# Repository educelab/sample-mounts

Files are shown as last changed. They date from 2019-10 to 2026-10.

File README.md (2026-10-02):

# Sample Mounts

3D-printable sample mounts (scroll cases, interface plates, spindles, and
trays) for scanner and beamline data acquisition.

User docs: https://educelab.github.io/sample-mounts/

## Models

Ready-to-print STLs. Variants are named after the parameters they were
rendered with (e.g. `SpindleBase-6.35mm.stl`, `SI Interface Plate - 200mm.stl`).

- **Mount discs and rings.** The standard base (`Generic Mount Disc`, and a
  65 mm version) and the ring it mates with.
- **Interface plates.** Adapt the mount disc to a specific scanner or
  beamline stage (SkyScan 1273, I12.EH1, SI).
- **Spindles.** Spindle bases and stoppers for several rod diameters.

## OpenSCAD

Parametric sources for the models. Parameters are top-level variables and can
be overridden on the command line:

```bash
openscad -o out.stl -D rod_type=2 "OpenSCAD/Spindle Base.scad"
```

Interface plates and spindle bases are built on `Generic Mount Disc*.scad`,
so changing the disc changes all of them.

`Fragment Trays.scad` and `Hanging Frame Case.scad` depend on
`Diamond Interface Plate.scad`, which isn't in this repo, so they won't render
as-is.

## scrollcase

Python generator for split scroll cases fit to a scroll mesh. Requires
[uv](https://docs.astral.sh/uv/):

```bash
cd scrollcase
uv run scrollcase defaults --style educelab.v1 > my-scroll.toml
uv run scrollcase build -c my-scroll.toml -o out/
```

See [Creating a scroll case](docs/creating-scroll-case.md) and the
[config reference](docs/scroll-case-config.md).

## utils

`SpiralLength.cpp` computes the length of an Archimedean spiral for use with
`Spiral Frame.scad`. It needs [GSL](https://www.gnu.org/software/gsl/):

```bash
cmake -S utils -B build && cmake --build build
```

## Docs

The user docs in `docs/` are built with MkDocs and published to GitHub Pages
on every push to `main`. To preview locally:

```bash
uvx --with mkdocs-material --with 'mkdocs<2' mkdocs serve
```

## License

AGPL-3.0. The scroll case's alignment and mesh pipeline are adapted from
[ScrollPrize/villa](https://github.com/ScrollPrize/villa/tree/main/foundation/scrollcase)
(MIT); see `scrollcase/src/scrollcase/LICENSE.villa`.

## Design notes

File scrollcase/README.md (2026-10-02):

# scrollcase

Generates the split honeycomb scroll case (left half with mount disc, right
half, and stand) around a scroll mesh. See
[`docs/creating-scroll-case.md`](../docs/creating-scroll-case.md) for the
workflow and [`docs/scroll-case-config.md`](../docs/scroll-case-config.md)
for every config option.

```bash
uv sync
uv run scrollcase build -c examples/generic.toml -o out/ --preview
uv run pytest
```

`--preview` also writes `<name>-preview.html`, a standalone 3D viewer with
per-part visibility, opacity, and an explode slider (three.js loads from a CDN).

Library use:

```python
from scrollcase import load_config
from scrollcase.pipeline import build

result = build(load_config("my-scroll.toml"), "out/")
```

## How it works

1. **Mesh stage** (`lining.py`, meshlib). Decimate and optionally smooth the
   scroll, fit the smallest enclosing cylinder, and rotate the scroll's wide
   direction into the split plane. Offset by `lining_offset` to get the
   cavity, split it at Y=0, extrude each half toward the split to remove
   undercuts, then offset by `wall_thickness` to get the lining wall.
2. **B-rep stage** (`case.py`, `mount_disc.py`, build123d). Shell, divider,
   mount disc, nubs, escape holes, labels, and stand, ported from the old
   OpenSCAD generator. `scad.py` provides OpenSCAD-style primitives so the
   port stays readable.
3. **Assembly** (`pipeline.py`). Each half is `(body ∪ wall) − cavity`.

meshlib's wheel bundles its own OpenCASCADE, which conflicts with
build123d's and crashes when both load in one process. The pipeline runs the
B-rep stage in `brep_worker` subprocesses and exchanges STLs. Don't import
`case` or build123d anywhere that imports `lining`.

`mount_disc.py` mirrors `OpenSCAD/Generic Mount Disc*.scad`, which the
interface plates and spindle bases still use. Keep them in sync.

`villa.2026-10` is checked against upstream's own code: run
`scripts/villa_reference.py` in an environment with villa's pinned
dependencies (see its docstring) to regenerate the reference data in
`tests/data/`. See [`docs/villa-2026-10-comparison.md`](../docs/villa-2026-10-comparison.md).

## Attribution

The alignment approach and mesh pipeline are adapted from the
[ScrollPrize/villa](https://github.com/ScrollPrize/villa/tree/main/foundation/scrollcase)
`scrollcase` package (MIT). `alignment.py` and `smallest_circle.py` are
derived from it; see `src/scrollcase/LICENSE.villa`.

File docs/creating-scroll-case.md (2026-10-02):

# Creating a scroll case

Scroll cases are generated by the `scrollcase` Python package in
[`scrollcase/`](https://github.com/educelab/sample-mounts/tree/main/scrollcase). Given a scroll mesh, it aligns the scroll,
builds a lining that follows its surface, and wraps the lining in the split
honeycomb case: left half (with mount disc), right half, and assembly stand.

## Requirements

- [uv](https://docs.astral.sh/uv/)
- (Optional) MeshLab, for repairing a mesh that isn't watertight

## Steps

1. **Prepare the mesh.** Any format meshlib reads (PLY, STL, OBJ). It should
   be a single watertight surface. Orientation and position don't matter. If
   it isn't in millimeters, set `scroll.scale`.

2. **Write a config.** Copy
   [`scrollcase/examples/template.toml`](https://github.com/educelab/sample-mounts/blob/main/scrollcase/examples/template.toml)
   next to your mesh:

   ```toml
   --8<-- "template.toml"
   ```

   Set `name`, `scroll.mesh` (relative to the config file), and the label.
   Every option is described in [the config reference](scroll-case-config.md).
   To start from every option instead, print a style's full config:

   ```bash
   cd scrollcase
   uv run scrollcase defaults --style educelab.v1 > my-scroll.toml
   ```

3. **Generate a draft.**

   ```bash
   uv run scrollcase -v build -c my-scroll.toml -o out/ --preview
   ```

   This writes `<name>-L.stl`, `-R.stl`, `-Stand.stl`, and `-Scroll.stl`. The
   scroll STL is the aligned scroll in case coordinates; load it with the
   halves in a viewer to check placement and clearances. `--preview` also
   writes and opens `<name>-preview.html`, which shows every part together.
   Make the halves see-through or explode them apart to check the fit, and
   use **Save snapshot** to save a PNG of the view.

4. **Adjust.**
   - The scroll is auto-aligned to the case axis, with its widest direction
     in the split plane. Use `scroll.rotate` (degrees, XYZ) to adjust it,
     e.g. to put a fragile edge away from the split.
   - Add `nubs.positions` as `[x, z]` pairs. Place them in the divider wall
     between the lining and the shell (the build prints both diameters).
   - `scroll.smoothing` (`"denoise"` or `"shrink_expand"`) simplifies a very
     detailed lining. Smoothing never cuts into the scroll.

5. **Print.** Overhang removal (on by default) extrudes each half's cavity
   toward the split, so the scroll can be lowered straight into either half
   without catching on the lining.

## What changed from the OpenSCAD generator

The manual MeshLab/MeshMixer lining steps, `modelRotate`/`modelTranslate`
positioning, and slow iterative overhang removal are now automatic. The case
design and parameters are the same; parameter names are snake_case.

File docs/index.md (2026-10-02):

# Sample Mounts

3D-printable sample mounts (scroll cases, interface plates, spindles, and
trays) for scanner and beamline data acquisition. Source and models are on
[GitHub](https://github.com/educelab/sample-mounts).

- **Models.** Ready-to-print STLs are in
  [`Models/`](https://github.com/educelab/sample-mounts/tree/main/Models).
- **OpenSCAD.** Parametric sources for most models are in
  [`OpenSCAD/`](https://github.com/educelab/sample-mounts/tree/main/OpenSCAD).
  Parameters are top-level variables and can be overridden with `-D`:

    ```bash
    openscad -o out.stl -D rod_type=2 "OpenSCAD/Spindle Base.scad"
    ```

- **Scroll cases.** Split scroll cases fit to a scroll mesh are generated by
  the `scrollcase` Python package. Start with
  [Creating a scroll case](creating-scroll-case.md), then see the
  [config reference](scroll-case-config.md) for every option.

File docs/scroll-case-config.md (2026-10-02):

# Scroll case config reference

Scroll cases are configured with a TOML file passed to `scrollcase build -c`.
Every key is optional; anything left out comes from the config's style
preset. Print a style's complete config:

```bash
uv run scrollcase defaults --style educelab.v1 > my-scroll.toml
```

Unknown keys are an error, so typos don't silently fall back to defaults.
Combinations that can't be built are also rejected when the config loads
(see [Valid combinations](#valid-combinations)). Lengths are in millimeters
and angles in degrees.

## Styles

`style` picks a preset of defaults for every key below. Your own values
override the preset key by key, so `[shell] type = "solid"` keeps the rest of
the preset's `[shell]` settings, including its marker rings.

| Style | Description |
|---|---|
| `educelab.v1` | The default: honeycomb shell with floor and lid, flat split, Generic Mount Disc, stand. The former OpenSCAD generator's design. |
| `villa.2026-10` | [ScrollPrize/villa's case](https://github.com/ScrollPrize/villa/tree/main/foundation/scrollcase) at commit `7d6a82c` (2026-10-01): no shell, curved split ending in round posts, square bolted caps with upstream's label layout, kinematic mount disc, 3 mm margins, no stand. |

Components mix freely within the [valid combinations](#valid-combinations),
e.g. villa's caps and kinematic disc around a honeycomb shell:

```toml
style = "educelab.v1"
[split]
type = "curve"
[ends]
type = "caps"
[mount]
type = "kinematic"
[stand]
enabled = false
```

`villa.2026-10` reproduces upstream's case bodies exactly; see the
[comparison](https://github.com/educelab/sample-mounts/blob/main/docs/villa-2026-10-comparison.md). The known differences are all in
the mesh stage: the scroll fit uses a tighter tolerance, the wide-axis
rotation normalizes its vector before taking the angle, `voxel_size` is
absolute (upstream uses 0.4% of the mesh diagonal), and `"denoise"`
smoothing uses `smoothing_amount` (upstream ignores its strength setting).

Released styles never change, so a config rebuilds the same case for as
long as it names the same style. A design update becomes a new version
(e.g. `educelab.v2`). Omitting `style` means `educelab.v1`, permanently.

**Case coordinates.** The case axis is +Z and the bottom of the shell is
Z=0; the mount disc sits below it, from Z=-12.5 to 0. The halves split on the
XZ plane: the left half (with the mount disc) is on the -Y side and the right
half is on the +Y side.

## Top level

| Key | Default | Description |
|---|---|---|
| `style` | `"educelab.v1"` | Preset to resolve the rest of the config against. See [Styles](#styles). |
| `name` | `"Scroll Case"` | Output file prefix: `<name>-L.stl`, `-R.stl`, `-Stand.stl`, `-Scroll.stl`. Overridden by `--name`. |
| `lining_offset` | `2.0` | Clearance between the scroll surface and the inside of the lining. Also the gap above and below the scroll. |
| `wall_thickness` | `2.0` | Thickness of the lining wall, shell, lid, and half of the divider. The floor is `max(2, wall_thickness)`. |
| `bottom_buffer` | `5.0` | Gap between the floor and the bottom of the lining. |
| `top_buffer` | `5.0` | Gap between the top of the lining and the lid. |
| `internal_gap` | `3.0` | Radial gap between the lining and the inside of the shell. |
| `overhang_removal` | `true` | Extrudes each half's cavity toward the split so the scroll can be lowered straight in. Turn off only to inspect the raw lining. |
| `voxel_size` | `0.4` | Resolution of the lining offsets and overhang removal. Smaller is more faithful but slower and uses more memory; the PHercParis scrolls peaked at 3.5–5 GB at 0.4. |

## `[scroll]`

The input mesh and how it is prepared and placed.

| Key | Default | Description |
|---|---|---|
| `mesh` | none | Scroll mesh (PLY, STL, or OBJ). A relative path is resolved against the config file. Overridden by the positional `mesh` argument. If unset, a generic cylinder is used. |
| `scale` | `1.0` | Multiplies the mesh coordinates. Use it if the mesh isn't in millimeters. |
| `auto_align` | `true` | Fits the smallest cylinder that encloses the scroll, stands the scroll up along +Z with its bottom at Z=0, and turns its widest direction into the split plane. With `false`, the mesh keeps its own orientation (its Z axis becomes the case axis) but is still centered on the axis with its bottom at Z=0. |
| `rotate` | `[0, 0, 0]` | Extra rotation in degrees about the X, then Y, then Z axes, applied after alignment. The scroll is then re-centered on the case axis, so only the orientation changes. Z spins the scroll about the case axis, e.g. `[0, 0, 90]` puts the widest direction across the split instead of in it. X/Y tilt it; the case grows to enclose the tilted scroll. |
| `translate` | `[0, 0, 0]` | Offset applied after re-centering. An X/Y offset deliberately moves the scroll off the case axis, and the case grows to enclose it. Z has no effect, because the scroll is always placed `lining_offset` above the cavity floor. |
| `decimate_max_error` | `0.05` | How far, at most, the simplified input mesh may deviate from the original. |
| `smoothing` | `"none"` | Simplifies a very detailed lining: `"denoise"` or `"shrink_expand"`. The smoothed result is merged with the original, so smoothing never cuts into the scroll. |
| `smoothing_amount` | `2.0` | For `"denoise"`, the smoothing strength (meshlib `gamma`). For `"shrink_expand"`, the shrink/expand distance in mm; larger values round off more detail. |
| `generic_diameter` | `76.0` | Diameter of the generic cylinder used when `mesh` is unset. |
| `generic_height` | `155.0` | Height of the generic cylinder used when `mesh` is unset. |

## `[split]`

The surface the two halves separate along. Every split is a profile
y = f(x) extruded along Z, so from anywhere in a half the scroll can move
straight along Y to the split; overhang removal relies on this.

| Key | Default | Description |
|---|---|---|
| `type` | `"plane"` | `"plane"`: the XZ plane. `"curve"`: ScrollPrize/villa's S-shaped split, made of two arcs, spanning the whole case out to the middle of the shell wall. A curved seam avoids a flat interface lined up with the beam, which shows up as a streak in CT. |
| `amplitude` | unset | How far the S bulges from the XZ plane. Unset means 0.2 × (span + `wall_thickness`), as upstream, where the span is the radius at the middle of the shell wall. Too large an amplitude is an error. |
| `flip` | `false` | Mirrors the S. |

With a curved split the divider follows the curve at constant thickness,
and nubs move along Y to sit on it.

## `[shell]`

The outer cylinder around the lining, including its floor and lid.

| Key | Default | Description |
|---|---|---|
| `type` | `"honeycomb"` | `"honeycomb"` (hexagonal cutouts), `"solid"`, or `"none"`. With `"none"` the case is just the lining, divider, and ends, as upstream; the divider then ends in round posts at the cavity edge. |
| `open_top` | `false` | Cuts away the upper shell on both sides, leaving an open cradle around the lining. |
| `marker_rings` | `true` | Raised rings at the cavity bottom, scroll bottom, scroll middle, scroll top, and cavity top, on a honeycomb or solid shell. Ignored with `type = "none"`, since there is no shell to put them on, so switching a preset to no shell doesn't also require turning them off. |

### `[shell.honeycomb]`

Hexagonal cutouts, used when `shell.type = "honeycomb"`. The floor, lid,
marker ring bands, and divider stay solid.

| Key | Default | Description |
|---|---|---|
| `hole_edges` | `6` | Number of sides on each hole. |
| `columns` | `12` | Holes around the circumference. Alternate rows are offset by half a column. |
| `spacing` | `1.5` | Width of the strips between holes. |

## `[ends]`

What closes the top and bottom of the case.

| Key | Default | Description |
|---|---|---|
| `type` | `"shell"` | `"shell"`: the shell's own floor and lid. `"caps"`: villa's square end caps, sized to the larger of the mount disc and the case (plus one `wall_thickness` on each side around a shell). Bolts through tabs on both sides clamp the halves together; the bottom cap has counterbored mounting holes and an engraved arrow; the top cap carries the label. |
| `cap_height` | `10.0` | Cap thickness. Also the width of the bolt tabs. |
| `corner_fillet` | `6.25` | Radius of the caps' corners. |
| `bolt_hole_diameter` | `5.0` | Clamping bolt clearance hole (M4, loose). |
| `bolt_counterbore_diameter` | `8.0` | Bolt head counterbore, on the +Y face of each tab. |
| `bolt_counterbore_depth` | `2.0` | |
| `nut_diameter` | `9.0` | Hex nut pocket, across corners, on the -Y face of each tab. |
| `nut_depth` | `3.5` | |
| `mount_hole_spacing` | `50.0` | Mounting holes in the bottom cap at (±spacing, ±spacing). The build fails if the counterbores don't fit on the cap, e.g. on a small case with no mount disc. |
| `mount_hole_diameter` | `6.8` | Mounting bolt clearance hole (M6). |
| `mount_counterbore_diameter` | `10.5` | Counterbored from the inside face of the bottom cap. |
| `mount_counterbore_depth` | `5.0` | |

The `cap_*`, `bolt_*`, `nut_*`, and `mount_*` keys only apply to caps.

## `[mount]`

The mount that attaches the left half to the scanner.

| Key | Default | Description |
|---|---|---|
| `type` | `"generic-112.5"` | `"generic-112.5"` or `"generic-65"`: the Generic Mount Disc of that diameter, matching `OpenSCAD/Generic Mount Disc*.scad`, with an orientation notch on its rim. `"kinematic"`: villa's 112.5 × 10 mm disc with three V-slots for a kinematic mount; the right half's side of its top is lowered 0.5 mm so the right half doesn't bind on it. `"none"`: no mount. |

## `[nubs]`

Alignment nubs on the left half's split face, with matching sockets on the
right half. Place them on the divider, outside the cavity and inside the
case: the build fails, naming the nub, if one isn't. `scrollcase build`
prints the lining and shell diameters. On a curved split each nub sits at
(x, f(x), z), still pointing along Y, with its base sunk into the divider so
it stays attached where the surface slopes.

| Key | Default | Description |
|---|---|---|
| `positions` | `[]` | `[x, z]` pairs, e.g. `[[-44, 20], [44, 150]]`. The nub is placed at X = -x, as in the old OpenSCAD generator. Odd-numbered entries (the 2nd, 4th, …) are rotated 45° into diamonds. |
| `size` | `4.0` | Width and height of each nub. |
| `depth` | `1.5` | How far each nub sticks out from the split face. |
| `margin` | `0.5` | Clearance on every side of the socket. |

## `[escape_holes]`

Four holes per half: two through the floor and two through the lid, placed at
±`angle` from the X axis in the gap between the lining and the shell. On the
left half, the floor holes go through the mount disc as well.

| Key | Default | Description |
|---|---|---|
| `enabled` | `false` | Adds the holes. |
| `offset` | `1.5` | Moves the holes outward from halfway between the lining and the shell. Holes that would be tangent to a shell surface are nudged inward by 0.1 mm. |
| `diameter` | `4.0` | Hole diameter. |
| `angle` | `15.0` | Angle of each hole from the X axis, in degrees. |

## `[label]`

With shell ends, the label is engraved on the bottom of the mount disc (left
half) and the bottom of the shell (right half), mirrored so it reads
correctly from below. It is also engraved on the stand's back plate, on the
face toward the case. With caps it goes on the top cap in upstream's layout:
`line1` once on each half, `line2`, and a generated `<lining D> x <cavity H>`
line.

| Key | Default | Description |
|---|---|---|
| `line1` | `""` | First line. Empty lines are skipped. |
| `line2` | `""` | Second line, placed 1.5 × `height` below the first. |
| `height` | `5.0` | Font size. |
| `depth` | `0.5` | Engraving depth. |
| `font` | `"Arial Rounded MT Bold"` | System font name. If the font isn't installed, Arial is used instead. OpenCASCADE's warning about this is hidden when the build succeeds. |

## `[stand]`

Cradle that holds the left half upright on its mount disc during assembly.

| Key | Default | Description |
|---|---|---|
| `enabled` | `true` | Builds `<name>-Stand.stl`. `--parts` defaults to `left,right`, plus `stand` when this is on. |
| `length_scale` | `1.0` | Stand length as a fraction of the case height. The top cradle moves with it. |

## Valid combinations

These are checked when the config loads, and the error names the keys
involved.

| Rule | Why |
|---|---|
| `ends.type = "shell"` requires a shell | The floor and lid are part of the shell. |
| `shell.open_top` requires `ends.type = "shell"` | It cuts away the shell's lid. |
| `escape_holes` require a shell | They sit in the gap between the lining and the shell. |
| `stand.enabled` requires a `generic-*` mount and `ends.type = "shell"` | The cradle is shaped around the Generic Mount Disc, its notch, and the round shell. |

## How the dimensions stack up

From the fitted scroll radius `r` and height `h`:

```
cavity diameter   = 2 (r + lining_offset)
lining diameter   = cavity diameter + 2 wall_thickness
shell inner diam. = lining diameter + 2 internal_gap
case diameter     = shell inner diam. + 2 wall_thickness

case height = floor + bottom_buffer
            + wall_thickness + (h + 2 lining_offset) + wall_thickness
            + top_buffer + lid
```

The floor is `max(2, wall_thickness)` and the lid is `wall_thickness`; with
caps both are `cap_height`. Without a shell, the case diameter is the
lining diameter.

`scrollcase build` prints the scroll, lining, shell, and case sizes.

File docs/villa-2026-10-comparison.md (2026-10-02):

# `villa.2026-10` vs upstream

How the `villa.2026-10` style compares with
[ScrollPrize/villa's scrollcase](https://github.com/ScrollPrize/villa/tree/main/foundation/scrollcase)
at commit `7d6a82c` (2026-10-01). Upstream was run in its own environment
with its pinned dependencies (build123d `30bbe96`, meshlib 3.0.5.215).
Comparisons done 2026-10-01.

## Case bodies: exact match

Upstream's `build_case` and our `left_body`/`right_body` were built for
four scroll sizes (radius × height in mm): 38 × 155, 20 × 60,
44.41 × 167.58, and 32.83 × 178.06. Upstream puts Z=0 at the scroll bottom,
so our bodies were shifted down by `scroll_z`.

For all eight bodies (left and right at each size), the volumes and
bounding boxes match, and the symmetric difference between ours and
upstream's is 0.000 mm³. This includes the caps, bolt tabs, nut pockets,
mounting holes, arrow, top-cap text, curved divider with end posts, and
kinematic disc with its 0.5 mm clearance.

`tests/test_villa_reference.py` keeps it that way, using reference volumes
and bounding boxes generated by `scrollcase/scripts/villa_reference.py`.

## End to end: PHercParis3 and PHercParis4

Both pipelines were run on `phercparis3-scaled.ply` and
`phercparis4-scaled.ply`: upstream's `build_lining`, `build_case`, and
`combine_brep_case_lining`, and our `scrollcase build` with
`style = "villa.2026-10"`.

| | Fitted radius | Fitted height | Holes (L + R) | Separate bodies (L / R) | Min. scroll clearance | Blocked slide-out paths |
|---|---|---|---|---|---|---|
| PHercParis3, upstream | 44.60 | 166.55 | 26 | 41 / 13 | 1.80 mm | 0 of 300 |
| PHercParis3, ours | 44.41 | 167.58 | 0 | 1 / 1 | 1.95 mm | 0 of 300 |
| PHercParis4, upstream | 32.93 | 178.05 | 2 | 1 / 1 | 1.82 mm | 0 of 300 |
| PHercParis4, ours | 32.83 | 178.06 | 0 | 1 / 1 | 1.94 mm | 0 of 300 |

- **Fit.** Our tighter fit tolerance gives a 0.1–0.2 mm smaller radius.
  Heights agree within 1 mm.
- **Mesh quality.** Upstream's PHercParis3 halves have open holes and many
  separate fragments; ours are closed single bodies.
- **Clearance.** The target is `lining_offset` = 2 mm. Upstream's coarser
  voxels (0.4% of the mesh diagonal, about 0.8 mm here) leave 1.8 mm; ours
  (0.4 mm) leave 1.95 mm.
- **Placement.** Our scrolls sit 180° about the case axis from upstream's.
  Both pipelines pick the wide axis's sign arbitrarily, and because the S
  is point-symmetric, a 180° turn swaps which part of the scroll goes in
  which half. Turned 180°, upstream's PHercParis4 scroll is within 0.45 mm
  (mean) of ours. PHercParis3 is also turned 6° by upstream's wide-axis
  calculation, which doesn't normalize its vector before `arccos`; turned
  180°, it's within 1.2 mm. Total case volume agrees within 0.1%; only the
  left/right split differs. For these two scrolls,
  `scroll.rotate = [0, 0, 180]` reproduces upstream's orientation.

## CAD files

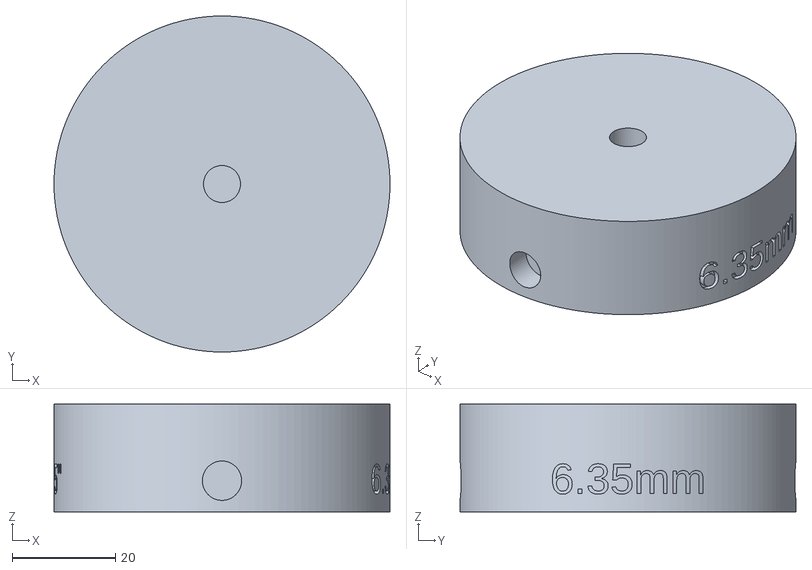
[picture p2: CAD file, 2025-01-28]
Models/SpindleBase-6.35mm.stl
65.0 x 65.0 x 20.8

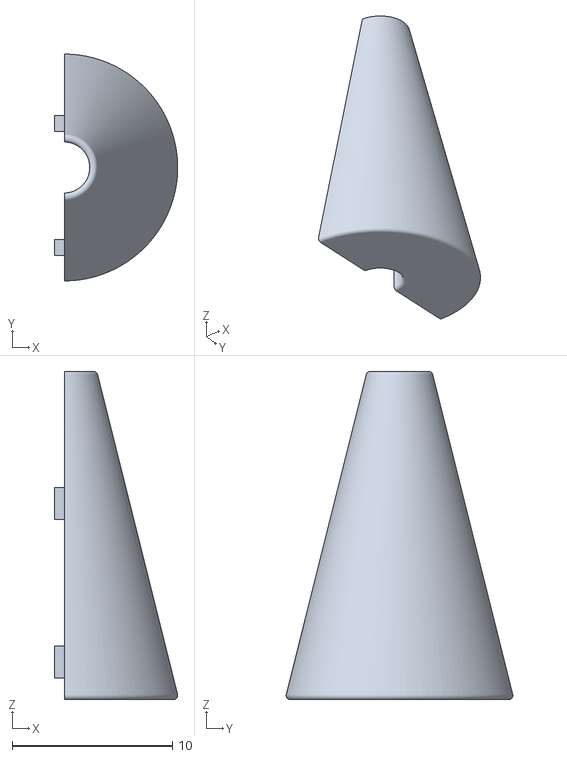
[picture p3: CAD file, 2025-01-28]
Models/SpindleStopper-3.175x20mm.stl
7.71 x 14.2 x 20.5

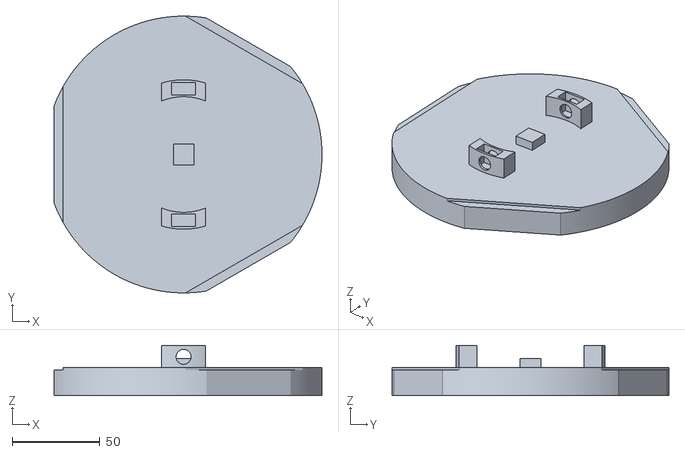
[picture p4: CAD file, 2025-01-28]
Models/SkyScan 1273 Interface Plate 65mm.stl
152.5 x 157.5 x 28.5

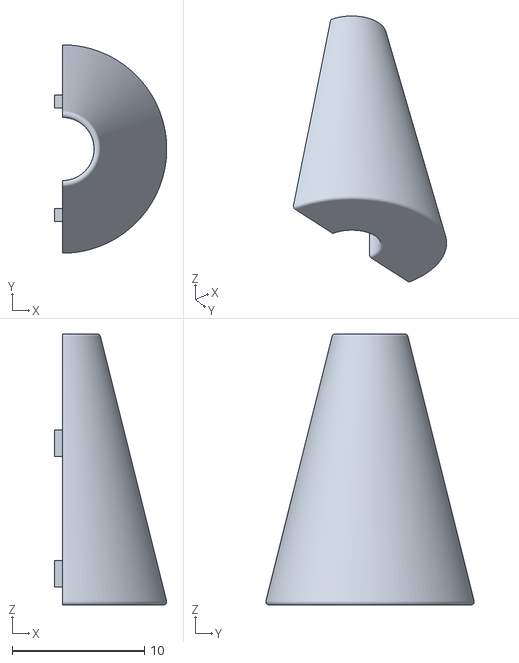
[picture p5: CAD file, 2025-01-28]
Models/SpindleStopper-4.7625x20mm.stl
8.51 x 15.8 x 20.5

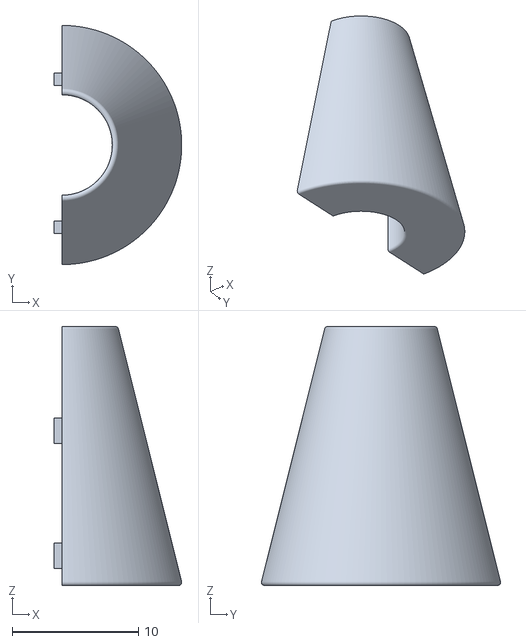
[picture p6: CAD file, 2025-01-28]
Models/SpindleStopper-7.9375x20mm.stl
10.1 x 18.9 x 20.5

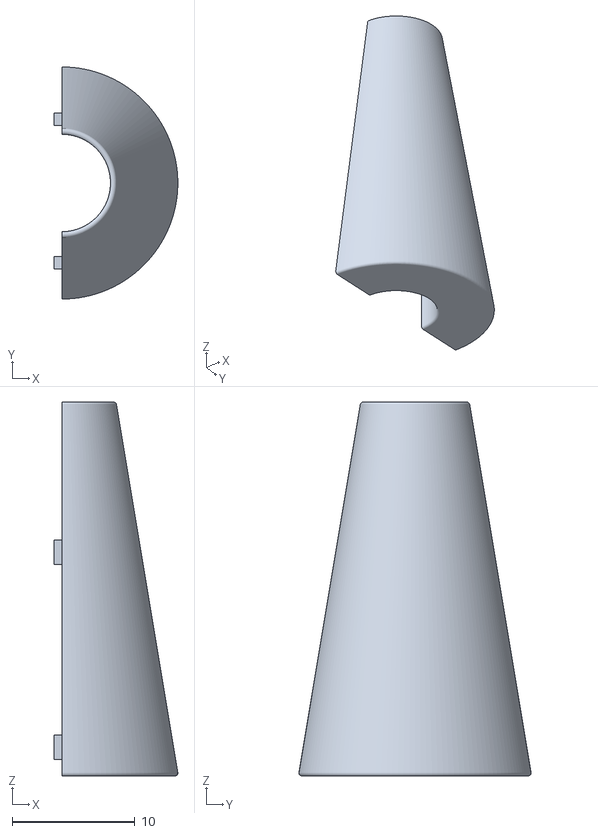
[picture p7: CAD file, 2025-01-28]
Models/SpindleStopper-7.9375x30mm.stl
10.1 x 18.9 x 30.5

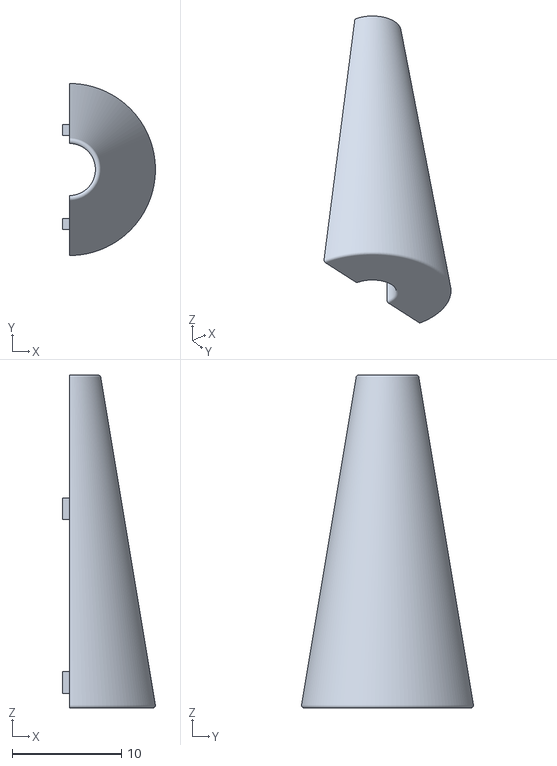
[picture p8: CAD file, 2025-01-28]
Models/SpindleStopper-4.7625x30mm.stl
8.51 x 15.8 x 30.5

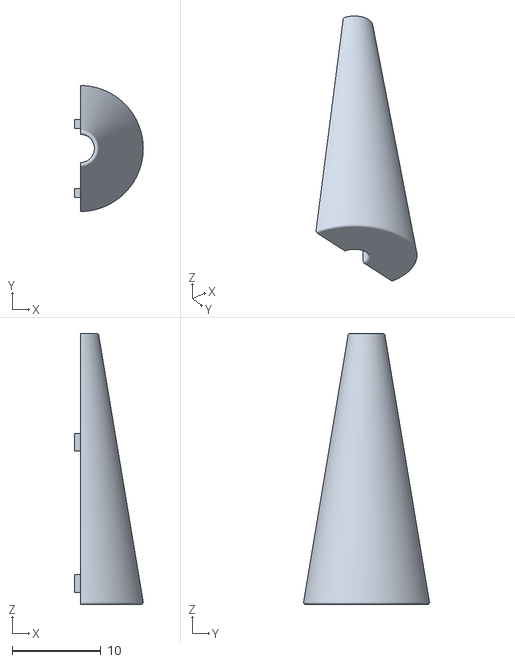
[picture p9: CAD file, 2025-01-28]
Models/SpindleStopper-3.175x30mm.stl
7.71 x 14.2 x 30.5

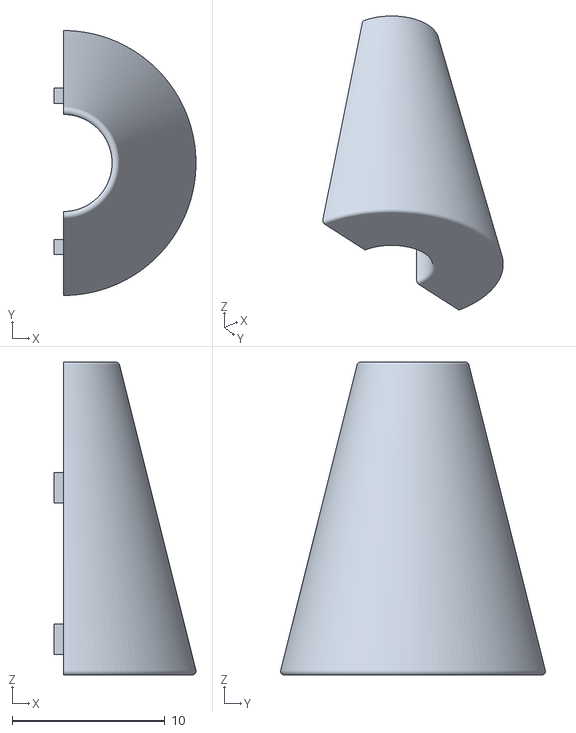
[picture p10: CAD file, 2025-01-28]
Models/SpindleStopper-6.35x20mm.stl
9.30 x 17.3 x 20.5

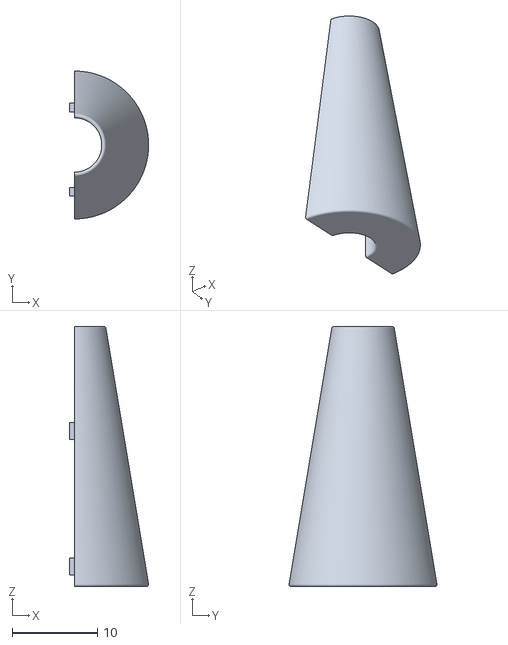
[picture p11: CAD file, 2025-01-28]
Models/SpindleStopper-6.35x30mm.stl
9.30 x 17.3 x 30.5

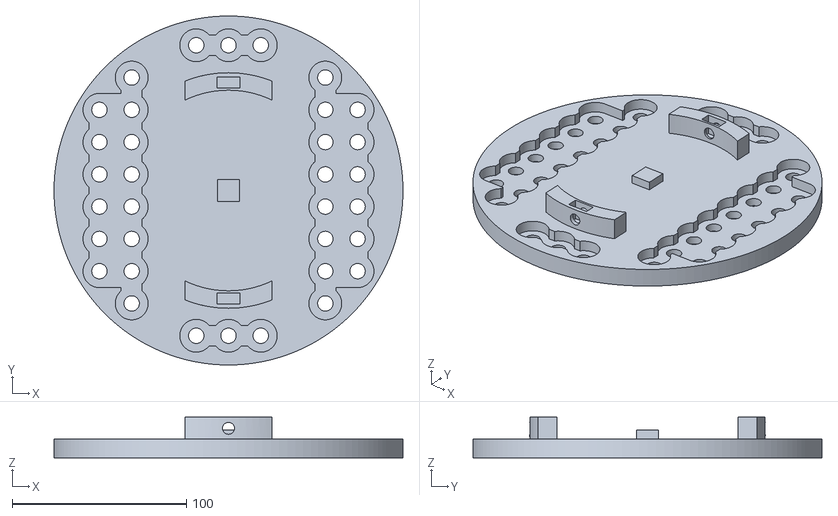
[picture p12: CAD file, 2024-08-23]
Models/SI Interface Plate - 200mm.stl
200.1 x 200.1 x 23.5

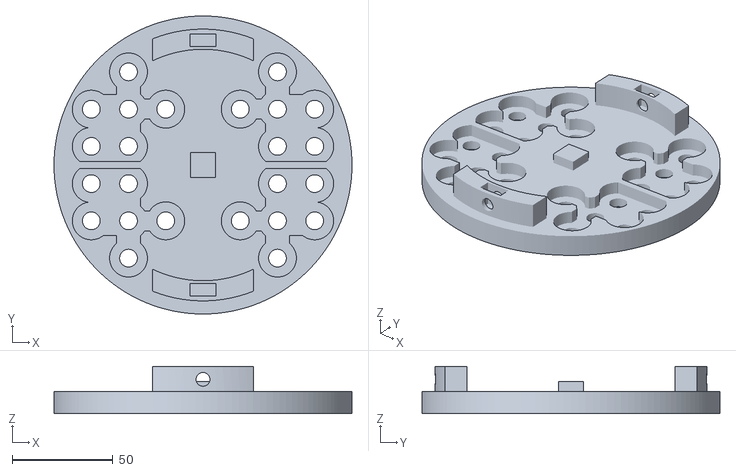
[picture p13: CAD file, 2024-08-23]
Models/SI Interface Plate - 147mm.stl
148.0 x 148.0 x 23.5

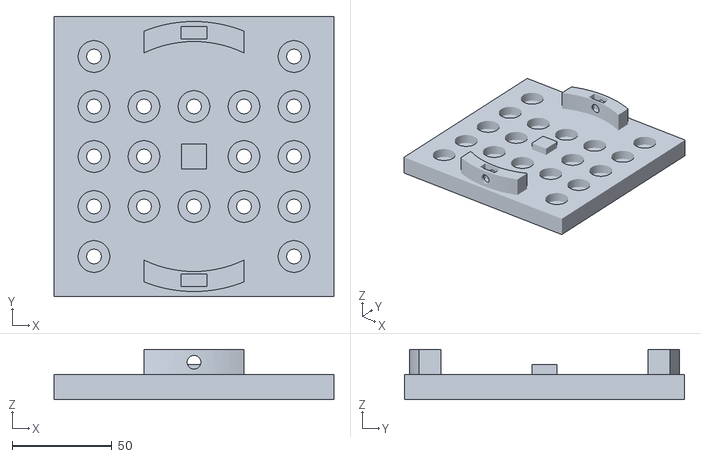
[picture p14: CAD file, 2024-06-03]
Models/I12.EH1 Lab Jack Interface Plate.stl
140.0 x 140.0 x 25.2

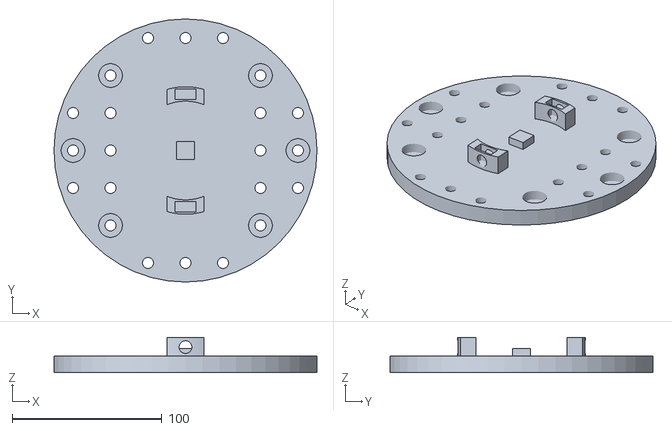
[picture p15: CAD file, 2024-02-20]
Models/I12.EH1 Interface Plate - 65mm.stl
175.4 x 175.4 x 23.5

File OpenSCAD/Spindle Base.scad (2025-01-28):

use <Generic Mount Disc 65mm.scad>;
use <cylinder_outer.scad>

baseRadius = GenericMountDisc_Diameter() / 2;
baseThickness = GenericMountDisc_Thickness() / 1.5;

// rod types:
// 0 -> 1/8"  -> 3.175mm
// 1 -> 3/16" -> 4.7625mm
// 2 -> 1/4"  -> 6.35mm
// 3 -> 5/16" -> 7.9375mm
rod_type = 0;

// internal variables
thicknesses_in = [1/8, 3/16, 1/4, 5/16];
eps=0.4;
thicknessIn = thicknesses_in[rod_type];
spindleThickness = thicknessIn * 25.4;
spindleRadius = eps + spindleThickness / 2;
spindleHeight = baseThickness + 100;

difference() {
  union() {
    GenericMountDisc();
    translate([0,0,GenericMountDisc_Thickness()]) cylinder_outer(h=baseThickness, r=baseRadius, fn=128);
  }

  translate([0, 0, 2 + GenericMountDisc_Thickness() / 2]) cylinder_outer(h=spindleHeight, r=spindleRadius);
  
  translate([-1,0,0]) intersection() {
  difference() {
    cylinder_outer(h=baseThickness*2, r=34.5, fn=128);
    cylinder_outer(h=baseThickness*2, r=32.5, fn=128);
  };
  translate([18,0,3.5])
  rotate([90, 0, 90]) linear_extrude(25) text(str(spindleThickness, "mm"), halign="center", size=6);
  }
  
  translate([1,0,0]) intersection() {
  difference() {
    cylinder_outer(h=baseThickness*2, r=34.5, fn=128);
    cylinder_outer(h=baseThickness*2, r=32.5, fn=128);
  };
  translate([-18,0,3.5])
  rotate([90, 0, 270]) linear_extrude(25) text(str(thicknessIn, "\""), halign="center", size=6);
  }
}

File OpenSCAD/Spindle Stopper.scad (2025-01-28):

use <cylinder_outer.scad>


// rod types:
// 0 -> 1/8"  -> 3.175mm
// 1 -> 3/16" -> 4.7625mm
// 2 -> 1/4"  -> 6.35mm
// 3 -> 5/16" -> 7.9375mm
rod_type = 3;
// stopper height (mm)
height = 20;

// internal variables
rod_diams = [3.175, 4.7625, 6.35, 7.93375];
bases = [10, 10, 10, 10];
lock1_positions = [0.5, 0.5, 0.55, 0.65];
lock2_positions = [0.275, 0.36, 0.44, 0.52];
eps = 0.4;
rounding = 0.25;
ring_diam = 6.35; 
ring_thickness = 1.778;
rod_diam = rod_diams[rod_type];
base = bases[rod_type];
lock1 = lock1_positions[rod_type];
lock2 = lock2_positions[rod_type];


module stopper(ring_cutout=false) {

hole = rod_diam;


difference() {
  rotate_extrude($fn=128)
  minkowski() {
    translate([rounding + hole/2, 0])
    polygon([[0,0],[base/2,0],[0,height]]);
    circle(rounding, $fn=64);
  }
  if(ring_cutout) {
    translate([0,0,height*.3]) cylinder_outer(d=ring_diam+eps, h=ring_thickness+eps, fn=128);
  }
}
}

box_w = base + rod_diam + rounding*2 + 1;
box_h = height + 1;
lock_depth = 1.25;

translate([2,0,0])
union() {
difference() {
  stopper();
  translate([0, base*lock1, 2.1]) cube([lock_depth,1,2], center=true);
  translate([0, -base*lock2, height*.6]) cube([lock_depth,1,2], center=true);
  translate([-box_w/2, 0, box_h/2 - rounding*2]) cube([box_w, box_w, box_h], center=true);
}
translate([0, -base*lock1, 2.1]) cube([lock_depth,1,2], center=true);
translate([0, base*lock2, height*.6]) cube([lock_depth,1,2], center=true);
}


/* 

Each half is identical, so only need one

translate([-2,0,0])
union() {
difference() {
  stopper();
  translate([0, -base*0.5, 2.1]) cube([lock_depth,1,2], center=true);
  translate([0, base*0.275, height*.6]) cube([lock_depth,1,2], center=true);
  translate([box_w/2, 0, box_h/2 - rounding*2]) cube([box_w, box_w, box_h], center=true);
}
translate([0, base*0.5, 2.1]) cube([lock_depth,1,2], center=true);
translate([0, -base*0.275, height*.6]) cube([lock_depth,1,2], center=true);
}
*/

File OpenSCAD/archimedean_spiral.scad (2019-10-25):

function polyMax(p) = [max([for(pi = p) pi[0]]), max([for(pi = p) pi[1]])];
function polyMin(p) = [min([for(pi = p) pi[0]]), min([for(pi = p) pi[1]])];
function polyMidPt(p) = (polyMin(p) + polyMax(p))/2;

// spirals     = how many spirals (positive=CCW, negative=CW)
// thickness   = how thick you want the arms to be
// startradius = beginning radius position
// spacing     = spacing between radial points
// startangle  = angle to begin first sweep
// armCenter   = 'true' armCenters the spiral arm thickness
// center      = 'true' center spiral on origin
// original from: https://www.thingiverse.com/thing:2945256
module archimedean_spiral_2d(spirals=1, thickness=1, spacing=1, startradius=1.0, startangle=0, armCenter=true, center=false) {
	t = thickness;
	s1 = (startradius / spacing) * 360.0;
	s2 = ((startradius + (abs(spirals)*spacing)) / spacing) * 360.0;
	angoff = ((-s1+startangle) % 360.0);
	a = sqrt(pow(spacing*abs(spirals)+startradius,2)/(pow(s2,2)*(pow(cos(s2),2) + pow(sin(s2),2))));
	points=[
		for(i = [s1+($fa - (s1 % $fa))-$fa:$fa:s2+($fa - (s2 % $fa))-$fa]) [
			(((i*a)+ ((armCenter) ? -t/2 : 0))*cos(sign(spirals)*(i+angoff))),
			(((i*a)+ ((armCenter) ? -t/2 : 0))*sin(sign(spirals)*(i+angoff)))
		]
	];
	points_inner=[
		for(i = [s2+($fa - (s2 % $fa))-$fa:-$fa:s1+($fa - (s1 % $fa))-$fa]) [
			(((i*a)+ ((armCenter) ? t/2 : t))*cos(sign(spirals)*(i+angoff))),
			(((i*a)+ ((armCenter) ? t/2 : t))*sin(sign(spirals)*(i+angoff)))
		]
	];
    
    translation = center ? -polyMidPt(concat(points,points_inner)) : [0,0];
	translate(translation) polygon(concat(points,points_inner));
}

module archimedean_spiral_3d(height = 5, spirals=1, thickness=1, spacing = 1, startradius = 1.0, startangle = 0, armCenter=true, center=false)
{
    linear_extrude(height=height){ 
        archimedean_spiral_2d(spirals=spirals, thickness=thickness, spacing=spacing, startradius=startradius, startangle=startangle, armCenter=armCenter, center=center); 
    }
}

// archimedean_spiral_3d(thickness=5, spirals=5, startradius=5, spacing=10, center=true);

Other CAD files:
Models/SpindleBase-3.175mm.stl
Models/SpindleBase-7.9375mm.stl
Models/SpindleBase-4.7625mm.stl
Models/Generic Mount Disc 65mm.stl
OpenSCAD/cylinder_outer.scad
Models/CBL Case Mounts Large.stl
Models/CBL Case Mounts Small.stl
Models/Generic Mount Disc.stl
Models/Generic Mount Ring 65mm.stl
Models/Generic Mount Ring.stl
Models/Generic Prop.stl
Models/Generic Scroll Case.stl
Models/I12.EH1 Interface Plate.stl
OpenSCAD/Fragment Trays.scad
OpenSCAD/Generic Mount Disc 65mm.scad
OpenSCAD/Generic Mount Disc.scad
OpenSCAD/Generic Mount Ring 65mm.scad
OpenSCAD/Generic Mount Ring.scad
OpenSCAD/Hanging Frame Case.scad
OpenSCAD/I12.EH1 Interface Plate.scad
OpenSCAD/I12.EH1 Lab Jack Interface Plate.scad
OpenSCAD/SI Interface Plate - 147mm.scad
OpenSCAD/SI Interface Plate - 200mm.scad
OpenSCAD/Scan Tray Generator.scad
OpenSCAD/SkyScan 1273 Interface Plate.scad
OpenSCAD/Spiral Frame.scad
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

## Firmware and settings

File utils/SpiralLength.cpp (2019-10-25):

#include <cmath>
#include <iostream>
#include <gsl/gsl_integration.h>
#include <gsl/gsl_math.h>

struct Params {
    double r0{0};
    double drdt{0};
};

double f(double theta, void* params)
{
    Params* p = static_cast<Params*>(params);
    auto base = gsl_pow_2(p->drdt * theta + p->r0);
    auto delta = gsl_pow_2(p->drdt);
    return std::sqrt(base + delta);
}

int main(int argc, char* argv[])
{
    if (argc < 4) {
        std::cout << "Usage: " << argv[0]
                  << " [start-radius] [spirals] [spacing]" << std::endl;
        return EXIT_FAILURE;
    }

    // Parameters
    Params params;
    params.r0 = std::stod(argv[1]);
    auto spirals = std::stod(argv[2]);
    auto spacing = std::stod(argv[3]);
    params.drdt = spacing / (2 * M_PI);
    double a = 0;
    double b = spirals * 2 * M_PI;

    // Integrate
    gsl_function F;
    F.function = &f;
    F.params = &params;

    auto w = gsl_integration_workspace_alloc(1000);
    double result, error;
    gsl_integration_qags(&F, a, b, 0, 1e-7, 1000, w, &result, &error);

    std::cout << "Spiral Length: " << result << std::endl;
    std::cout << "Error: " << error << std::endl;
}

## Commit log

2019-04-10 add mock scan chamber or tray scad file
    [mockScanChamberOrTray.scad]
2019-10-25 Add preview mode for positioning the lining. Add escapeOffset option for adjusting the offset hole positions.
    [CBL Case Mounts Large.stl, CBL Case Mounts Small.stl, Diamond Interface Mount Ring.stl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]
2024-05-30 Update Scroll Case Generator for 202407 scan
    [Scroll Case Generator.scad]
2024-05-31 Positively extrude the lining wall before diffing out the extruded linings, to make sure the wall keeps its thickness where there had been large overhangs
    [Scroll Case Generator.scad]
2024-06-03 Update Diamond interface plate to rectangular version for lab jack
    [Diamond Interface Plate.scad, Diamond Interface Plate.stl]
2024-08-23 Updates for SI project
    [Diamond Interface Mount Ring.stl, Diamond Interface Plate.scad, Diamond Interface Plate.stl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]
2024-08-23 Update README, rename some models
    [I12.EH1 Interface Plate - 65mm.stl, I12.EH1 Interface Plate.scad, I12.EH1 Interface Plate.stl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]
2026-10-01 Replace OpenSCAD scroll case generator with Python scrollcase package (#1)
    * Replace OpenSCAD scroll case generator with Python scrollcase package
    Port the split honeycomb scroll case to build123d and automate lining
    construction with a meshlib pipeline adapted from ScrollPrize/villa's
    scrollcase: cylinder-fit alignment, offset cavity, flat split at Y=0,
    undercut removal toward the split, and lining wall offset.
    The B-rep and mesh stages run in separate processes because meshlib
    bundles a conflicting OpenCASCADE. Removes Scroll Case Generator.scad,
    GenCase-Generic.sh, and OverhangRemover.cpp.
    * Add config reference and re-center scr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
    [Generic Mount Disc 65mm.scad, Generic Mount Disc.scad, Scroll Case Generator.scad]
2026-10-02 Composable scroll case components and versioned styles (educelab.v1, villa.2026-10) (#2)
    * Restructure scrollcase config into components and style presets
    Replace the flat case flags with typed sections ([split], [shell],
    [ends], [mount], [stand]) and resolve configs as dataclass defaults,
    then a named style preset, then user values. educelab.v1 is the current
    design and the permanent default; golden files in tests/presets freeze
    each released preset. Invalid component combinations are rejected when
    the config loads.
    No geometry change: generic, fully featured, solid/65 mm, and
    PHercParis3 builds match the previous outputs exactly.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
2026-10-02 Update GitHub Actions off Node 20 and pin to commit hashes (#4)
    Bump checkout, setup-uv, upload-pages-artifact, and deploy-pages to
    their latest Node 24 releases, pinned by commit hash. setup-uv no
    longer publishes major tags. Add Dependabot to keep the pins current.
